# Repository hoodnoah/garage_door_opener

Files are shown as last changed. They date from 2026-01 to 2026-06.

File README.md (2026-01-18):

# ESP32 Rust Development Environment

A Nix-based development environment for ESP32 Rust projects. Uses the official [esp-rs/esp-idf-template](https://github.com/esp-rs/esp-idf-template) for project generation, ensuring version compatibility is maintained by the esp-rs team.

## Quick Start

```bash
nix develop                  # Enter development shell
just init my_project         # Generate Rust project (interactive)
just setup                   # Install ESP toolchain (one-time)
# Restart shell to pick up toolchain
just build                   # Compile
just flash                   # Flash to device and monitor
```

## What This Template Provides

This template provides the development environment and conveniences:

| File | Purpose |
|---|---|
| `flake.nix` | Nix dev shell with system dependencies |
| `.envrc` | Direnv integration for auto-loading |
| `justfile` | Convenience commands |
| `partitions.csv` | Flash partition layout |
| `.env.example` | Template for WiFi/MQTT secrets |

The actual Rust project files (`Cargo.toml`, `src/`, `.cargo/`, etc.) are generated by running `just init`, which uses the official esp-rs template. This ensures dependency versions stay compatible with ESP-IDF.

## Commands

| Command | Description |
|---|---|
| `just init <name>` | Generate Rust project using esp-rs template |
| `just setup` | Install ESP toolchain |
| `just build` | Debug build |
| `just build-release` | Release build (size-optimized) |
| `just flash` | Flash and monitor |
| `just flash-only` | Flash without monitor |
| `just monitor` | Serial monitor only |
| `just clean` | Remove build artifacts |
| `just clean-all` | Remove build artifacts and ESP-IDF cache |
| `just size` | Show binary size breakdown |

## Configuration

### Target Selection

When running `just init`, you'll be prompted to select your target chip (ESP32, ESP32-S3, ESP32-C3, etc.). The template handles the configuration automatically.

### Environment Variables

Copy `.env.example` to `.env` for compile-time configuration (WiFi credentials, etc.):

```bash
cp .env.example .env
```

### Flash Partitions

`partitions.csv` defines the flash layout. Adjust sizes based on your needs and flash size.

## Using as a GitHub Template

1. On GitHub, go to repository **Settings** > **General**
2. Check **Template repository**

Then create new projects via:
- GitHub UI: Click **Use this template**
- CLI: `gh repo create my-project --template USERNAME/esp32_template --clone`

After creating, run `just init <name>` to generate the Rust project.

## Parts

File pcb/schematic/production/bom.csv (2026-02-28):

Designator | Footprint | Quantity | Value | LCSC Part #
C1, C5, C6 | 0805 | 3 | 10uF | C440198
C2 | 0805 | 1 | 1uF | C28323
C3 | 0805 | 1 | 100nF | C49678
C4 | CP_EIA-3216-18_Kemet-A_HandSolder | 1 | 22uF Tantalum | C45783
D2, D3 | D_SOD-123 | 2 | D_Schottky | C8598
D4 | D_SOD-123 | 1 | 1N4148 | C81598
J5 | USB_C_Receptacle_HRO_TYPE-C-31-M-12 | 1 | USB_C_Receptacle_USB2.0_16P | C165948
Q1 | SOT-23 | 1 | MMBT3904 | C2145
R1, R8, R9 | 0805 | 3 | 1k | C17513
R10, R11, R2, R3, R4, R5 | 0805 | 6 | 10k | C17414
R6, R7 | 0805 | 2 | 5.1k | C27834
SW1 | SW_SPST_TS-1088-xR025 | 1 | BOOT_BTN | C720477
SW2 | SW_SPST_TS-1088-xR025 | 1 | RESET_BTN | C720477
U1 | ESP32-C3-WROOM-02 | 1 | ESP32-C3-WROOM-02 | C2934560
U2 | SOT-223-3_TabPin2 | 1 | AMS1117-3.3 | C6186

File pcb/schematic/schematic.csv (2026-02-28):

Comment | Designator | Footprint | JLCPCB Part #(optional) | Quantity
RESET_BTN | SW2 | SW_SPST_TS-1088-xR025 | C720477 | 1
BOOT_BTN | SW1 | SW_SPST_TS-1088-xR025 | C720477 | 1
10K | R2 | R_0805_2012Metric |  | 1
USB_C_Receptacle_USB2.0_16P | J5 | USB_C_Receptacle_HRO_TYPE-C-31-M-12 |  | 1
D_Schottky | D2,D3 | D_SOD-123 | C64885 | 2
10uF | C5,C6,C1 | C_0805_2012Metric |  | 3
10k | R5,R3,R4,R11,R10 | R_0805_2012Metric |  | 5
1uF | C2 | C_0805_2012Metric |  | 1
5.1k | R6,R7 | R_0805_2012Metric |  | 2
1k | R9,R1,R8 | R_0805_2012Metric |  | 3
22uF Tantalum | C4 | CP_EIA-3216-18_Kemet-A_HandSolder | C45783 | 1
100nF | C3 | C_0805_2012Metric |  | 1
ESP32-C3-WROOM-02 | U1 | ESP32-C3-WROOM-02 |  | 1
AMS1117-3.3 | U2 | SOT-223-3_TabPin2 | C6186 | 1
1N4148 | D4 | D_SOD-123 | C7420318 | 1
MMBT3904 | Q1 | SOT-23 | C7420357 | 1

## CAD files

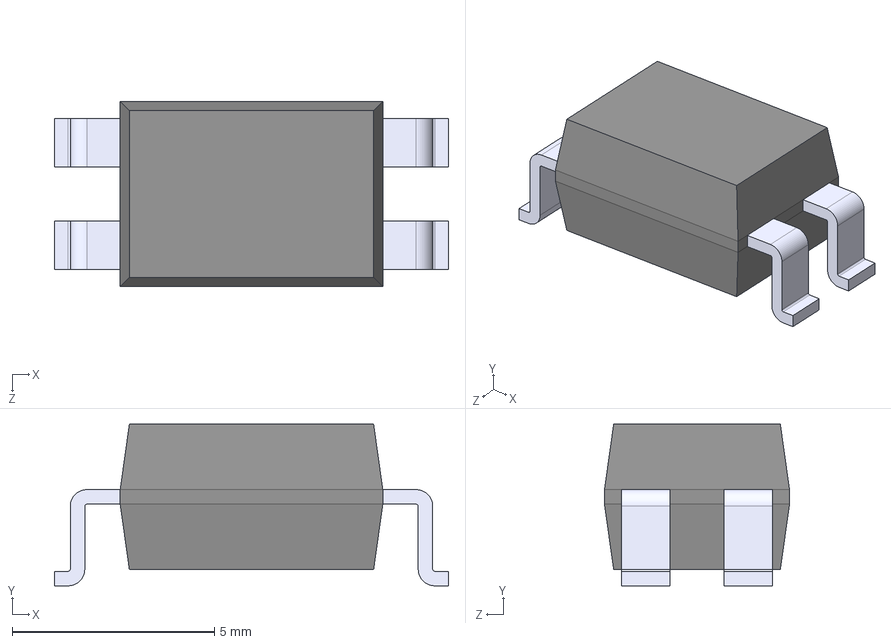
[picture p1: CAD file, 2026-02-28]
pcb/kicad_libraries/PC817X2NIP1B/PC817X2NIP1B.step
9.75 x 4.00 x 4.58 mm

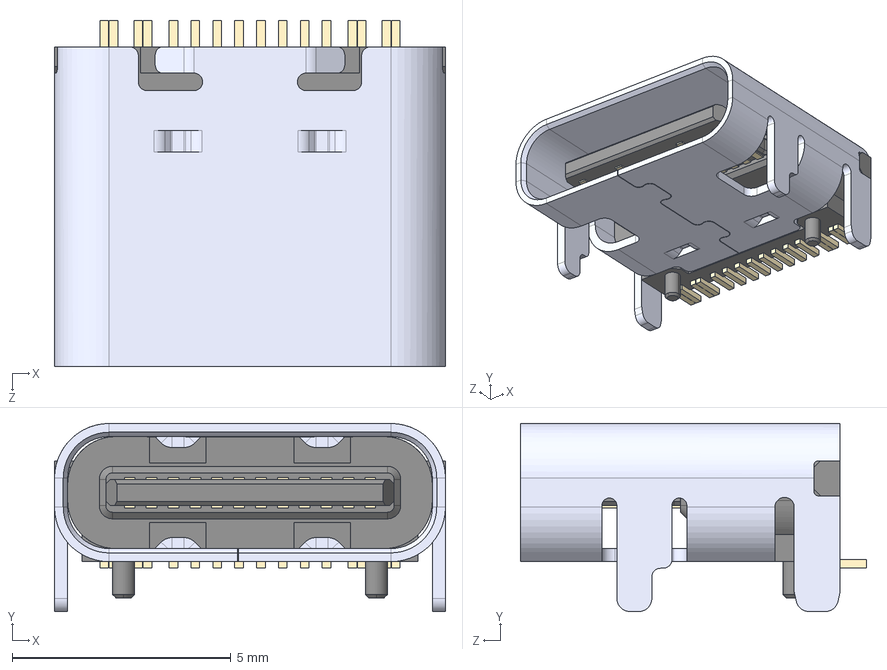
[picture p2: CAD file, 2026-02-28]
pcb/kicad_libraries/TYPE-C-31-M-12/TYPE-C-31-M-12--3DModel-STEP-56544.STEP
8.94 x 4.30 x 7.90 mm

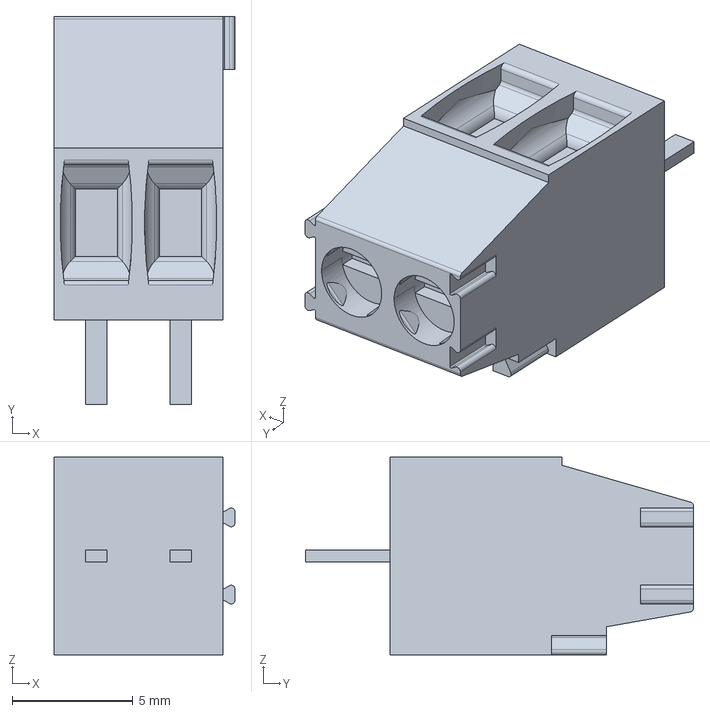
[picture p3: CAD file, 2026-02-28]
pcb/kicad_libraries/284391-2/284391-2.step
7.50 x 16.1 x 8.20 mm

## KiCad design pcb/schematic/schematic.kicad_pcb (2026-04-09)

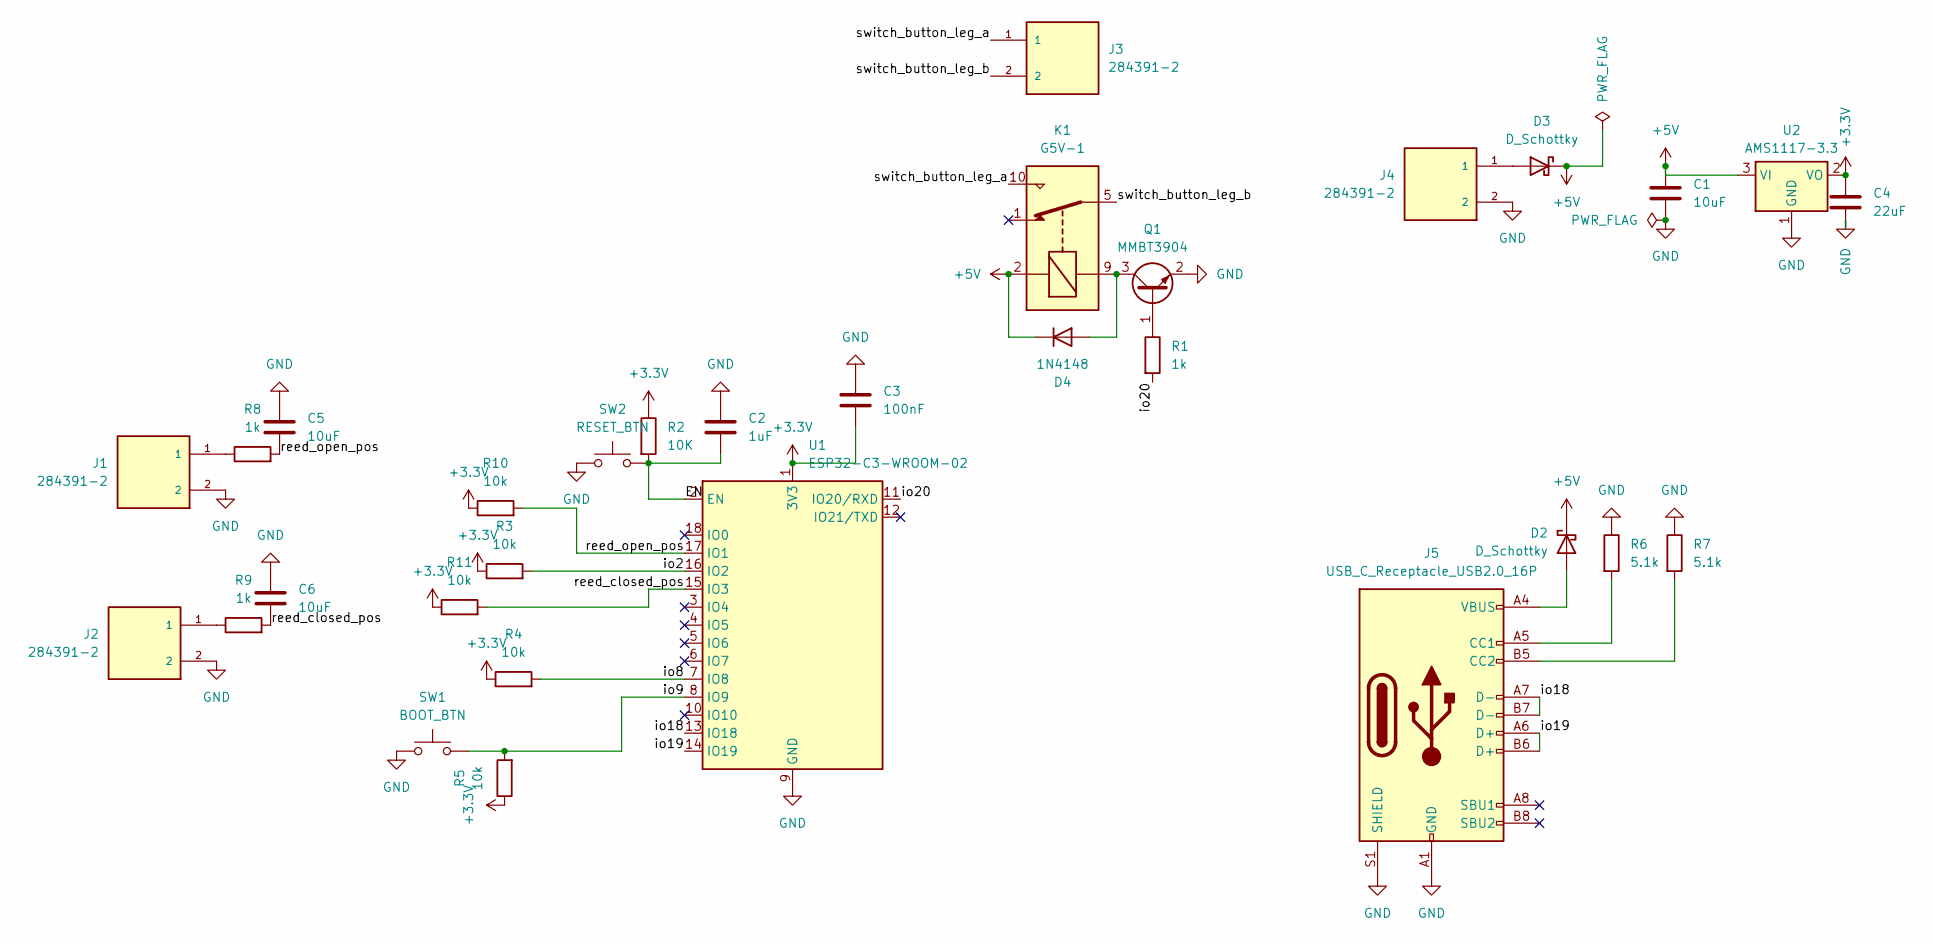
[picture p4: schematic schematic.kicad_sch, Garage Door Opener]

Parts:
C1, C5, C6: 10uF; C_0805_2012Metric; LCSC Part # C440198
C2: 1uF; C_0805_2012Metric; LCSC Part # C28323
C3: 100nF; C_0805_2012Metric; LCSC Part # C49678
C4: 22uF; C_0805_2012Metric; LCSC Part # C45783
D2, D3: D_Schottky; D_SOD-123; LCSC Part # C8598
D4: 1N4148; D_SOD-123; LCSC Part # C81598
J1, J2, J3, J4: 284391-2; TE_284391-2; PARTREV C; jlcpcb_part_no C3820579
J5: USB_C_Receptacle_USB2.0_16P; USB_C_Receptacle_HRO_TYPE-C-31-M-12; LCSC Part # C165948
K1: G5V-1; Relay_SPDT_Omron_G5V-1
Q1: MMBT3904; SOT-23; LCSC Part # C2145
R1, R8, R9: 1k; R_0805_2012Metric; LCSC Part # C17513
R2: 10K; R_0805_2012Metric; LCSC Part # C17414
R3, R4, R5, R10, R11: 10k; R_0805_2012Metric; LCSC Part # C17414
R6, R7: 5.1k; R_0805_2012Metric; LCSC Part # C27834
SW1: BOOT_BTN; SW_SPST_TS-1088-xR025; LCSC Part # C720477
SW2: RESET_BTN; SW_SPST_TS-1088-xR025; LCSC Part # C720477
U1: ESP32-C3-WROOM-02; LCSC Part # C2934560
U2: AMS1117-3.3; SOT-223-3_TabPin2; LCSC Part # C6186

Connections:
+3.3V: C3.2, C4.1, R2.1, R3.1, R4.1, R5.1, R10.1, R11.1, U1.1 (3V3), U2.2 (VO)
+5V: C1.1, D2.1 (K), D3.1 (K), D4.1 (K), K1.2, U2.3 (VI)
/EN: C2.2, R2.2, SW2.2, U1.2 (EN)
/io2: R3.2, U1.16 (IO2)
/io8: R4.2, U1.7 (IO8)
/io9: R5.2, SW1.2, U1.8 (IO9)
/io18: J5.A7 (D-), J5.B7 (D-), U1.13 (IO18)
/io19: J5.A6 (D+), J5.B6 (D+), U1.14 (IO19)
/io20: R1.2, U1.11 (IO20/RXD)
/reed_closed_pos: C6.2, R9.2, R11.2, U1.15 (IO3)
/reed_open_pos: C5.2, R8.2, R10.2, U1.17 (IO1)
/switch_button_leg_a: J3.1, K1.10
/switch_button_leg_b: J3.2, K1.5, K1.6
GND: C1.2, C2.1, C3.1, C4.2, C5.1, C6.1, J1.2, J2.2, J4.2, J5.A1 (GND), J5.A12 (GND), J5.B1 (GND), J5.B12 (GND), J5.S1 (SHIELD), Q1.2 (E), R6.1, R7.1, SW1.1, SW2.1, U1.9 (GND), U1.19 (GND), U2.1 (GND)
unnamed: D2.2 (A), J5.A4 (VBUS), J5.A9 (VBUS), J5.B4 (VBUS), J5.B9 (VBUS)
unnamed: D3.2 (A), J4.1
unnamed: D4.2 (A), K1.9, Q1.3 (C)
unnamed: J1.1, R8.1
unnamed: J2.1, R9.1
unnamed: J5.A5 (CC1), R6.2
unnamed: J5.B5 (CC2), R7.2
unnamed: Q1.1 (B), R1.1

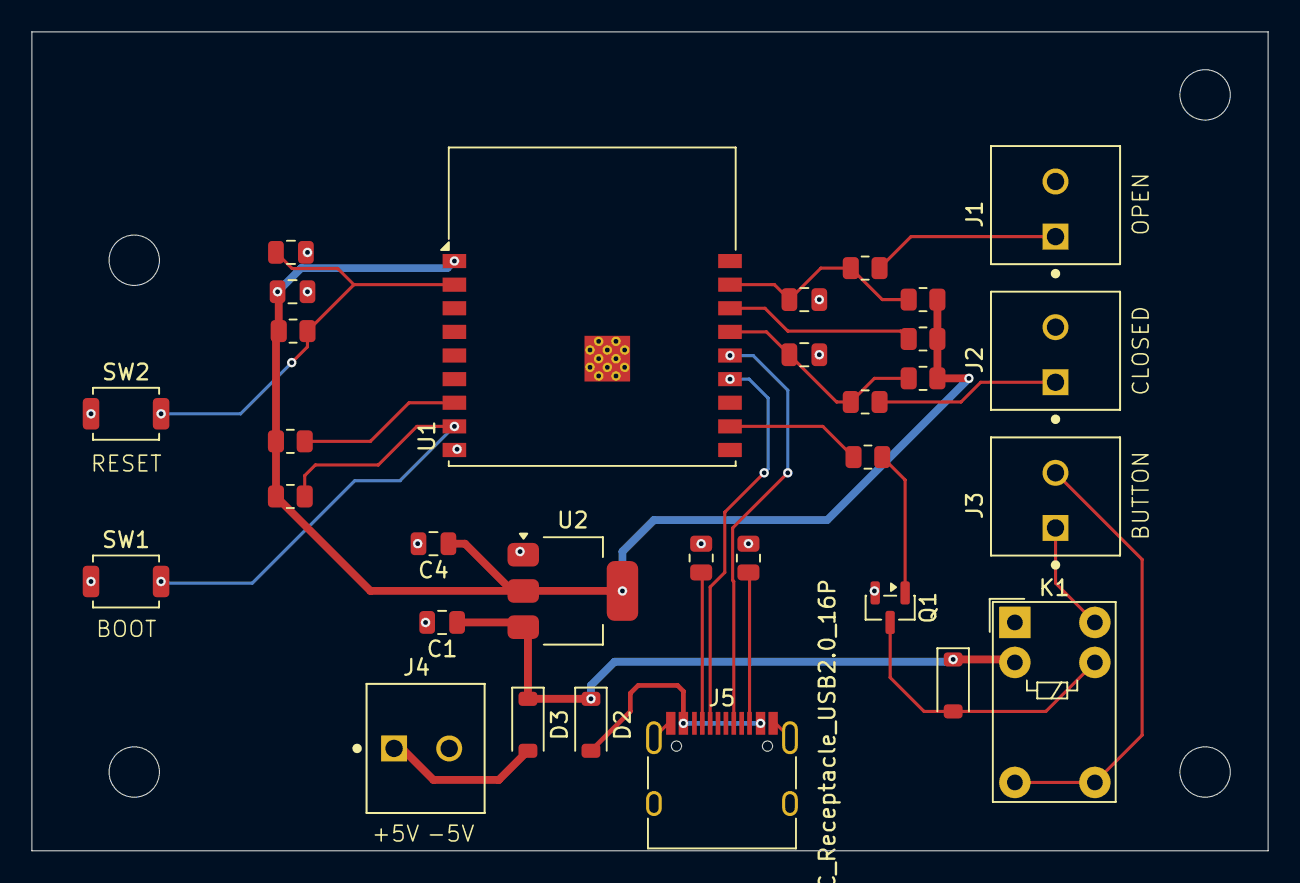
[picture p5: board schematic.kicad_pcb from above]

Board: 2 copper layers, 78.5 x 52.0 mm, 31 parts (0 on the bottom side), 22 nets.

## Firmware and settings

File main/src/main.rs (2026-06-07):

mod button;
mod connections_handler;
mod garage_door_controller;
mod mqtt;
mod reed_switch;
mod wifi;

use std::time::Duration;

use button::Button;
use connections_handler::{MqttVars, WifiVars};
use esp_idf_svc::{
    hal::{delay::FreeRtos, gpio::IOPin, peripherals::Peripherals},
    systime::EspSystemTime,
};
use garage_door_controller::{ControllerError, GarageDoorController};
use mqtt::GarageCommand;
use reed_switch::ReedSwitch;

use crate::connections_handler::ConnectionsHandler;

const WIFI_SSID: &str = env!("WIFI_SSID");
const WIFI_PASSWORD: &str = env!("WIFI_PASSWORD");
const MQTT_ENDPOINT: &str = env!("MQTT_ENDPOINT");
const MQTT_USER: &str = env!("MQTT_USER");
const MQTT_PASS: &str = env!("MQTT_PASS");

const LOOP_DELAY_MS: u32 = 100;
const WIFI_CHECK_INTERVAL: Duration = Duration::from_secs(5);
const WIFI_RETRY_INTERVAL_MS: u32 = 10_000;
const STATUS_PUBLISH_INTERVAL: Duration = Duration::from_secs(60);
const REBOOT_TIMEOUT: Duration = Duration::from_secs(5 * 60);

fn main() -> anyhow::Result<()> {
    esp_idf_svc::sys::link_patches();
    esp_idf_svc::log::EspLogger::initialize_default();

    let peripherals = Peripherals::take().unwrap();

    // Reed switches: GPIO3 = closed position, GPIO1 = open position
    let closed_switch = ReedSwitch::new(peripherals.pins.gpio3.downgrade())?;
    let open_switch = ReedSwitch::new(peripherals.pins.gpio1.downgrade())?;

    // Button: GPIO20 - pulses high to trigger the garage door opener
    let button = Button::new(peripherals.pins.gpio20.downgrade())?;

    // Garage door controller wraps both reed switches and the state machine
    let mut door_controller = GarageDoorController::new(open_switch, closed_switch, button)?;

    // Connections controller
    let wifi_vars = WifiVars::new(
        WIFI_SSID.to_string(),
        WIFI_PASSWORD.to_string(),
        WIFI_CHECK_INTERVAL,
    );
    let mqtt_vars = MqttVars::new(
        MQTT_ENDPOINT.to_string(),
        MQTT_USER.to_string(),
        MQTT_PASS.to_string(),
        STATUS_PUBLISH_INTERVAL,
    );
    let mut connections_handler = ConnectionsHandler::new(wifi_vars, mqtt_vars);

    // WiFi — retry indefinitely so a slow-booting router after a power outage
    // doesn't kill the whole app permanently
    match connections_handler.wifi_connect(peripherals.modem) {
        Ok(_) => {}
        Err(_) if connections_handler.has_wifi_handler() => loop {
            // retry if wifi_handler new worked
            match connections_handler.wifi_reconnect() {
                Ok(_) => break,
                Err(e) => {
                    log::warn!("WiFi retrying: {:?}", e);
                    FreeRtos::delay_ms(WIFI_RETRY_INTERVAL_MS);
                }
            }
        },
        Err(e) => {
            // new() itself failed, modem is gone. Needs reboot.
            log::error!("WiFi init failed unrecoverably: {:?}; restarting", e);
            esp_idf_svc::hal::reset::restart();
        }
    }

    // MQTT
    log::info!("Connecting to MQTT: {}", MQTT_ENDPOINT);
    loop {
        match connections_handler.mqtt_connect() {
            Ok(_) => break,
            Err(e) => log::warn!("MQTT connect failed: {:?}, retrying...", e),
        }
    }
    log::info!("MQTT ready");

    let mut last_ok = EspSystemTime {}.now();

    loop {
        // --- Update door state machine ---
        let state_changed = door_controller.update();
        let door_state = door_controller.state();

        if let Some(cmd) = connections_handler.tick(door_state, state_changed) {
            log::info!(
                "Received command: {:?} (current state: {:?})",
                cmd,
                door_state
            );

            match cmd {
                GarageCommand::Open => {
                    if let Err(e) = door_controller.try_open() {
                        match &e {
                            ControllerError::InvalidState(s) => {
                                log::warn!("Open ignored: door is {}", s)
                            }
                            ControllerError::HardwareError(_) => {
                                log::error!("Failed to open garage door: {}", e);
                                connections_handler
                                    .mqtt_publish_error(format!("Open cmd error: {}", e));
                            }
                        }
                    }
                }
                GarageCommand::Close => {
                    if let Err(e) = door_controller.try_close() {
                        match &e {
                            ControllerError::InvalidState(s) => {
                                log::warn!("Close ignored: door is {}", s)
                            }
                            ControllerError::HardwareError(_) => {
                                log::error!("Failed to close garage door: {}", e);
                                connections_handler
                                    .mqtt_publish_error(format!("Close cmd error: {}", e));
                            }
                        }
                    }
                }
            }
        }

        if connections_handler.is_healthy() {
            last_ok = EspSystemTime {}.now();
        } else if (EspSystemTime {}.now() - last_ok) >= REBOOT_TIMEOUT {
            log::error!("Connectivity dead too long; restarting");
            esp_idf_svc::hal::reset::restart();
        }

        FreeRtos::delay_ms(LOOP_DELAY_MS);
    }
}

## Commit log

2026-01-23 finalize state machine implementation, implement reed_switch, relay, garage_door_controller abstractions, retrofit mqtt/wifi libs
2026-02-25 working first version
    [partitions.csv]
2026-02-25 fully tested on breadboard, ready for prototype on actual unit
2026-02-28 PCB v1
    [284391-2.step, PC817X2NIP1B.step, TYPE-C-31-M-12--3DModel-STEP-56544.STEP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]
2026-03-02 update footprint of C4 capacitor to 0805
    [schematic.kicad_pcb, schematic.kicad_sch]
2026-03-13 update pin assignments, fix silkscreen on boot, reset buttons
    [main.rs]
2026-03-13 fix silkscreen for boot, reset buttons
    [schematic.kicad_pcb]
2026-04-09 pcb updates
    [schematic.kicad_pcb]
2026-04-09 fix: if the mcu came up before Home-Assistant and timed out (e.g. during power outage), main loop would return on error
    [main.rs]
2026-04-09 update reed switch to remove fields which are set but never read
2026-04-09 remove illusory states from reed switch; read initial value and set to that on creation
2026-04-09 fix minor error in main
    [main.rs]
2026-06-07 Disconnect fix (#1)
    * add reboot signal for long-term-lost mqtt connection
    * add handler for connections
    * fold new connections_handler into main.rs
    * clean up niggling bugs
    * bump Cargo version number
    [main.rs]
